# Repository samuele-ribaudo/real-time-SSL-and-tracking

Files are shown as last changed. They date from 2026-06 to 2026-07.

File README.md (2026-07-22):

# Real-Time Sound Source Localization and Tracking System

| Name | Matr. | Email |
|---|---|---|
| Samuele Ribaudo | 03821248 | samuele.ribaudo@tum.de |
| Hong Yan Jun  | 03813507 | go75kes@mytum.de |

> To see the engineering challenges we encountered and our solutions to overcome them, check out the [technical report ↗](documentation/technical_report.pdf)

## 1. Project structure

```text
.
├── code/                     # Project's firmware and STM32 build configuration
├── hardware/                 # Schematic files and custom structural designs
├── documentation/            # Academic documentation and project presentations
├── resources/                # External reference documentation
└── testing/                  # Standalone testing frameworks
```

> NOTE: every main directory in this repository contains a dedicated `README.md`. Please refer to those local files for thorough setup steps, configuration details, and specialized technical overviews relevant to each module.

---

## 2. Project overview

This project is a robotic "hearing" system that can detect where a sound is coming from and automatically turn to face it.

Using an STM32 microcontroller and two standard microphones, the system acts like a pair of human ears. When a person speaks, the system calculates the sound's origin and uses a servo motor to physically rotate the sensor array toward the speaker. It is designed to mimic a human neck's 180° range of motion. If a sound moves beyond what the system can physically reach, an onboard RGB LED signals a visual warning, acting as a modular trigger that would theoretically tell a larger humanoid robot to rotate its entire body.

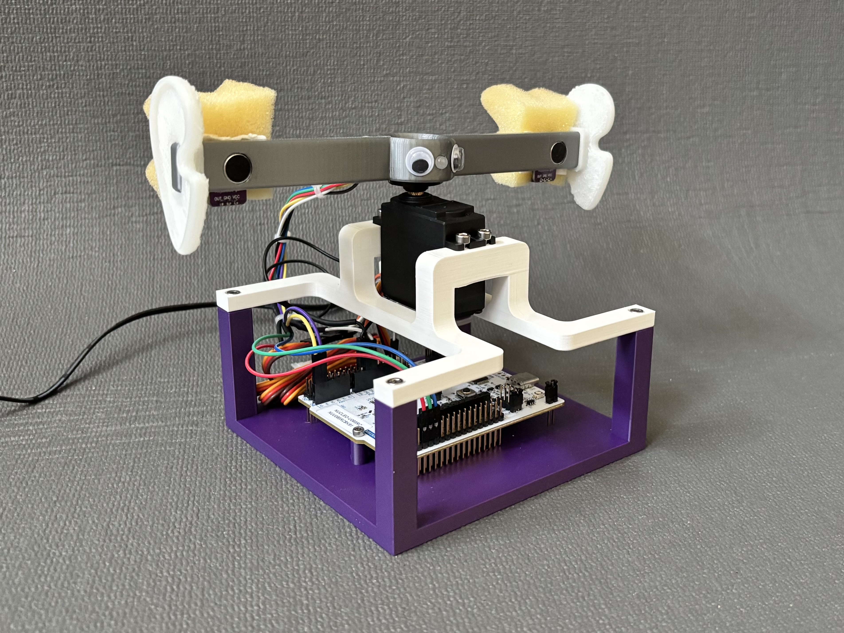
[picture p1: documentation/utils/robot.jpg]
acutal robot

> Figure: The final robotic project

---

## 3. Detailed system description

At a technical level, this project implements an embedded Sound Source Localization (SSL) and tracking system utilizing a NUCLEO-U083RC microcontroller developed within the STM32CubeIDE environment. The system continuously records environmental audio via two analog microphones spaced at a fixed distance. Using cross-correlation algorithms and digital filters, the system calculates the Time Delay of Arrival (TDOA) between the microphones to determine the precise azimuth angle of a human speaker.

To overcome the processing limitations of the micro controller and the physical realities of robotics, the system employs clever hardware-software design. It uses an acoustic foam baffle to eliminate the front-back "cone of confusion", calculates all math algorithms from scratch without relying on pre-built DSP libraries, and utilizes a strict "Listen-Compute-Move" state machine to prevent mechanical servo noise from corrupting the audio buffers. A 180° servo motor dynamically actuates the sensor array using a "relative-to-absolute" coordinate mapping to track the sound source.

---
## 4. Required materials & assembly

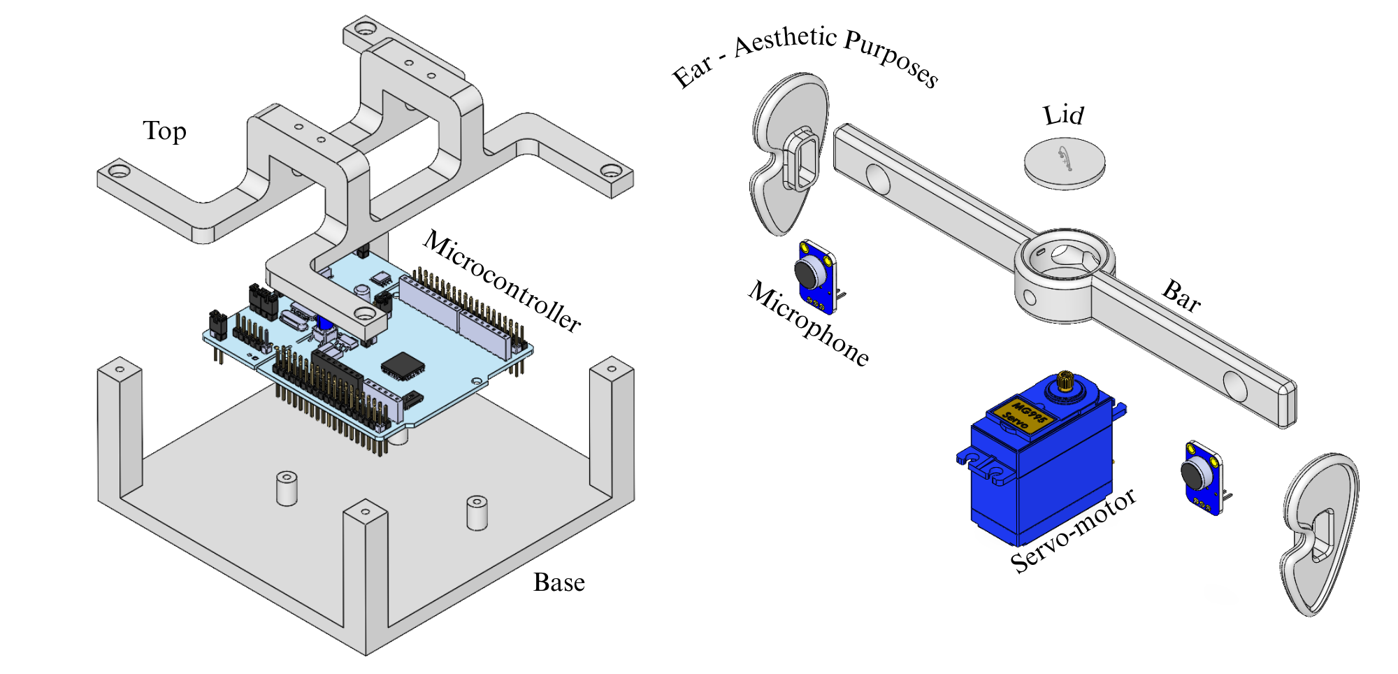
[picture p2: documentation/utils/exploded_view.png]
exploded view

> Figure: Exploded view of the system

| **Component** | **Qty** | **Description** |
| --- | --- | --- |
| NUCLEO-U083RC Development Board | 1 | The central processing unit of the system. It handles the high-speed ADC sampling via DMA, executes the mathematical cross-correlation algorithms, maintains the global coordinate tracking variables, and outputs the PWM control signals. | 
| MAX4466 analog microphones | 2 | Two independent analog microphones capture the environmental audio.|
| 180° servo motor | 1 | The mechanical actuator that rotates the sensor frame. |
| Acoustic foam block | 1 | High-density foam sponge to block rear audio signals. |
| RGB LED | 1 | A 4 pin RGB LED that provides real-time visual feedback of the state machine. It acts as a crucial flag for modular robotic design, flashing red when the target escapes the 180° physical field of hearing to trigger a "handoff" to a theoretical humanoid torso. |
| 330 Ohm resistor | 3 | Resistors placed in series with the RGB LED channels to prevent overcurrent damage. |
| PLA and TPU filament (3D Printing) | 1 | Material for printing the frame, board, servo mounts and ears (TPU). |
| Assorted wires | 1 | General circuit routing and power distribution. |

---
## 5. Physical connections & pin mapping

The system architecture utilizes dedicated hardware peripherals on the NUCLEO-U083RC board to handle high-speed data acquisition and actuation without blocking core application logic. The diagram below details the exact physical signal and power routing for each system component.

```text
                                ┌───────────────────────────────┐
                                │     STM32U083RC (Nucleo)      │                               5V power supply
                                │                               │                             ┌────────────────┐
                                │                          [GND]│─────────────────────────────│o  GND          │
                                │                          [VDD]│───┬─────────────────────────│o  5V           │
        Analog Left Mic         │                               │   │   180° Servo Morot      └────────────────┘
    ┌────────────────────┐      │                               │   │  ┌──────────────────┐
    │     OUT / Signal  o│─────>│[PC0]                          │   └──│o  VCC            │
    │              VCC  o│──────│[5V]                     [PA15]│─────>│o  PWM signal     │
    │              GND  o│──────│[GND]                     [GND]│──────│o  GND            │
    └────────────────────┘      │         ┌───────────┐         │      └──────────────────┘
                                │         │           │         │
        Analog Right Mic        │         │   STM32   │         │           RGB LED
    ┌────────────────────┐      │         │           │         │      ┌──────────────────┐
    │     OUT / Signal  o│─────>│[PC1]    └───────────┘   [PB13]│─────>│o  Red channel    │
    │              VCC  o│──────│[5V]                     [PB14]│─────>│o  Green channel  │
    │              GND  o│──────│[GND]                    [PB15]│─────>│o  Blue channel   │
    └────────────────────┘      │                          [GND]│──────│o  GND            │
                                │                               │      └──────────────────┘
                                └───────────────────────────────┘
```

To improve system readability and simplify debugging, we adopted a standardized, purpose-driven wire coloring scheme:

| Wire color | Purpose / Connection |
| --- | --- |
| White | Main 5V power supply line routed to the components. |
| Black | Common Ground (GND) connection to establish a shared reference plane. |
| Red | Digital control for the RGB LED Red channel. |
| Green | Digital control for the RGB LED Green channel. |
| Blue | Digital control for the RGB LED Blue channel. |
| Orange | Dedicated PWM signal line to control the 180° servo motor actuation. |
| Purple | Analog output signal transmission from the right microphone. |
| Yellow | Analog output signal transmission from the left microphone. |

---
## 6. MCU peripherals configuration

#### Timer 2 (PWM)

* **Clock Source**: Internal clock (16 MHz).
* **Channel 1**: PWM Generation CH1 (pin PA15).
* **Counter Settings**:
    * Prescaler (PSC): 15
    * Counter Mode: Up
    * Counter Period (ARR): 19999
    * Auto-reload preload: Enable

* **PWM Generation Channel 1**:
    * Mode: PWM mode 1
    * Pulse: 1500
    * CH Polarity: High

* **Configuration Logic**: Dividing the 16 MHz clock by 15 + 1 configures the timer to run at exactly 1 MHz, meaning 1 timer tick equals 1 microsecond. Counting to 19999 + 1 ticks creates a 20 ms period (50 Hz). Setting the initial Pulse to 1500 (1.5 ms) guarantees that the motor centers immediately upon power-up.

#### Timer 3 (ADC)

* **Clock Source**: Internal clock (16 MHz).
* **Counter Settings**:
    * Prescaler (PSC): 0
    * Counter Mode: Up
    * Counter Period (ARR): 319
    * Trigger Event Selection (TRGO): Update Event

#### ADC

* **Channels Enabled**: CH0 (PC0) and CH1 (PC1)
* **Resolution**: 12-bit resolution
* **External Trigger Conversion Source**: Timer 3 Trigger Out event (TRGO)
* **External Trigger Conversion Edge**: Rising Edge
* **Scan Conversion Mode**: Enabled
* **Number of Conversions**: 2

#### DMA

* **Direction**: Peripheral to memory
* **Mode**: Normal mode
* **Data Width**: 16-bit (half word)

#### GPIO LED

* **Pins**: PB13, PB14, and PB15 configured as GPIO Output.
* **Hardware Labels**: PB13 → LED_R, PB14 → LED_G, PB15 → LED_B.

---

## 7. The FSM & tracking logic breakdown

Because servo gears create acoustic noise, the system cannot listen and move at the same time. To address this limitation, the system relies on a strict, sequential FSM:

```mermaid
stateDiagram-v2
    direction TB
    
    [*] --> STATE_LISTEN
    
    %% Forward flow
    STATE_LISTEN --> STATE_COMPUTE : DMA buffer full
    STATE_COMPUTE --> STATE_ACTUATE : Sound detected OR<br>Inactivity timeout
    
    %% Branching out of ACTUATE
    STATE_ACTUATE --> STATE_OUT_OF_BOUNDS : Out-of-bounds<br>flag set
    STATE_ACTUATE --> STATE_SETTLE : Movement<br>within bounds
    
    %% Return paths (Grouped visually)
    STATE_COMPUTE --> STATE_LISTEN : No sound AND<br>Timeout pending
    STATE_SETTLE --> STATE_LISTEN : Mechanical delay<br>finished
    STATE_OUT_OF_BOUNDS --> STATE_LISTEN : Flashing finished
```
> Figure: State transition diagram for the acoustic localization and tracking pipeline.

* `STATE_LISTEN` (Blue): The servo is locked while the ADC+DMA pipeline records 1024 audio samples. Once the buffer is full, the DMA interrupt wakes the CPU and transitions the system to the compute phase.

* `STATE_COMPUTE` (Blue): Recording halts and the raw data is split and passed through the DSP pipeline.
    * If a sound is detected, the system calculates the angle offset, applies it to the current angle (flagging if it exceeds physical limits), and moves to `STATE_ACTUATE`.
    * If no sound is detected, the system checks an inactivity timeout. If the silence exceeds the maximum allowed time and the servo is not already centered, it targets the center position and moves to `STATE_ACTUATE`. Otherwise, it simply rolls back to `STATE_LISTEN`.

* `STATE_ACTUATE` (Green): The MCU updates the servo's position. If an out-of-bounds value was flagged during computation, the FSM transitions directly to `STATE_OUT_OF_BOUNDS`. If the movement is within normal limits, it proceeds to `STATE_SETTLE`.

* `STATE_SETTLE` (Green): A brief, blocking delay allows all mechanical servo vibrations to dissipate before the system safely loops back to `STATE_LISTEN`.

* `STATE_OUT_OF_BOUNDS` (Red Flash): The out-of-bounds flag is cleared, and the system flashes the red LED to provide a visual warning that the target exceeded the 180° physical limit. Once the flashing sequence finishes, it returns to `STATE_LISTEN`.

---

## 8. System validation and results

The digital signal processing (DSP) pipeline was fully validated on the NUCLEO-U083RC microcontroller, proving that the real-time cross-correlation and Time Delay of Arrival (TDOA) algorithms accurately track acoustic sources.

### 8.1 Signal filtering performance
To isolate human speech from environmental noise, the incoming audio passes through a custom 6th-order Butterworth bandpass filter (300 Hz to 3000 Hz). As shown below, the filter successfully suppresses low-frequency hums (100 Hz) and high-frequency noise (6 kHz), completely flattening the noise floor to provide clean signals for cross-correlation:

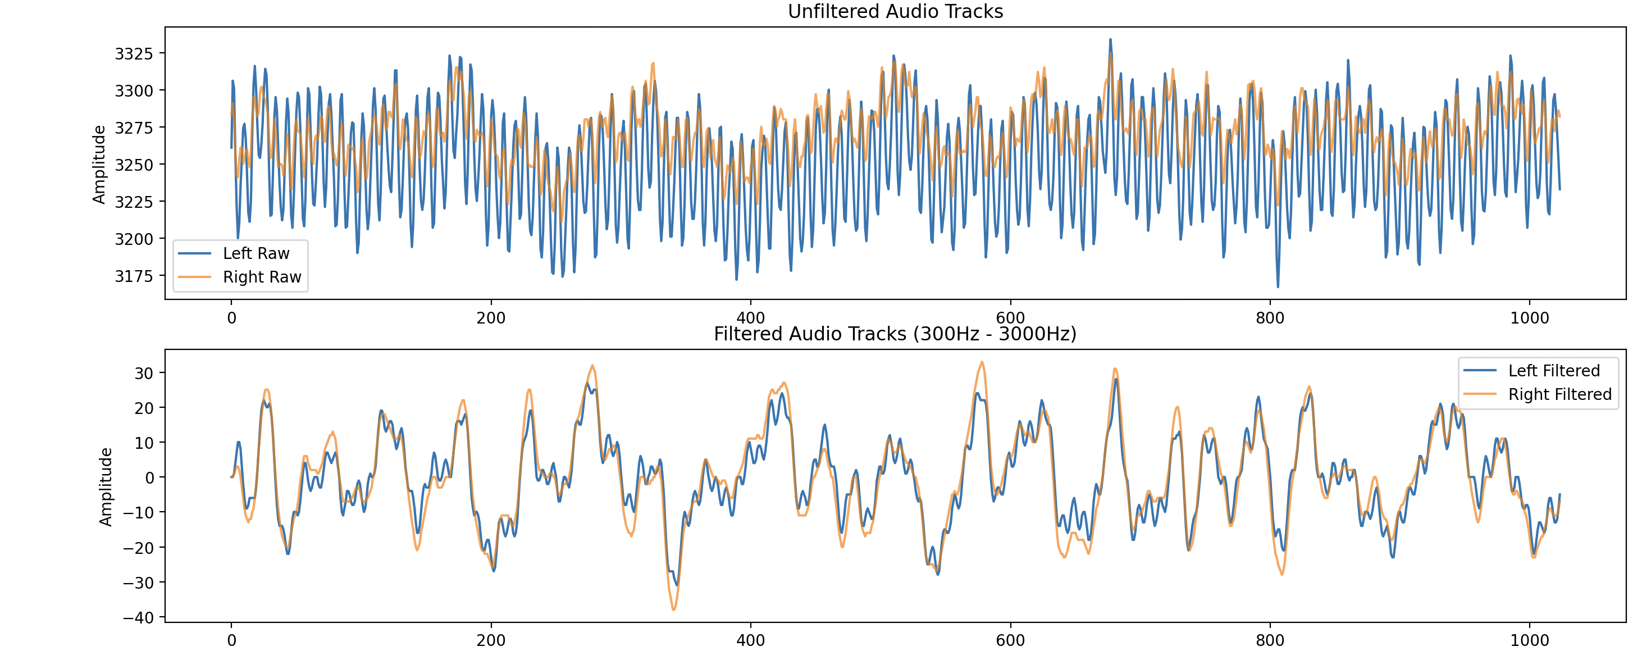
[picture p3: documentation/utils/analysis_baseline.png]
Signal Filtering Output

> Figure: Raw recording with environmental noise disturbances (top) and the resulting clean, flattened noise floor after 6th-order filtering (bottom).

### 8.2 Pipeline execution and sound tracking
When a sound is detected, the conditioned signals undergo a boundary-optimized cross-correlation to pinpoint the exact time delay. 

The system validation capture below highlights a successful test with a sound source on the right side. The pipeline filters out heavy background noise and produces a sharp, singular cross-correlation peak at a 22-sample lag. This precise shift allows the geometric logic to accurately calculate the angle and smoothly actuate the servo motor toward the target.

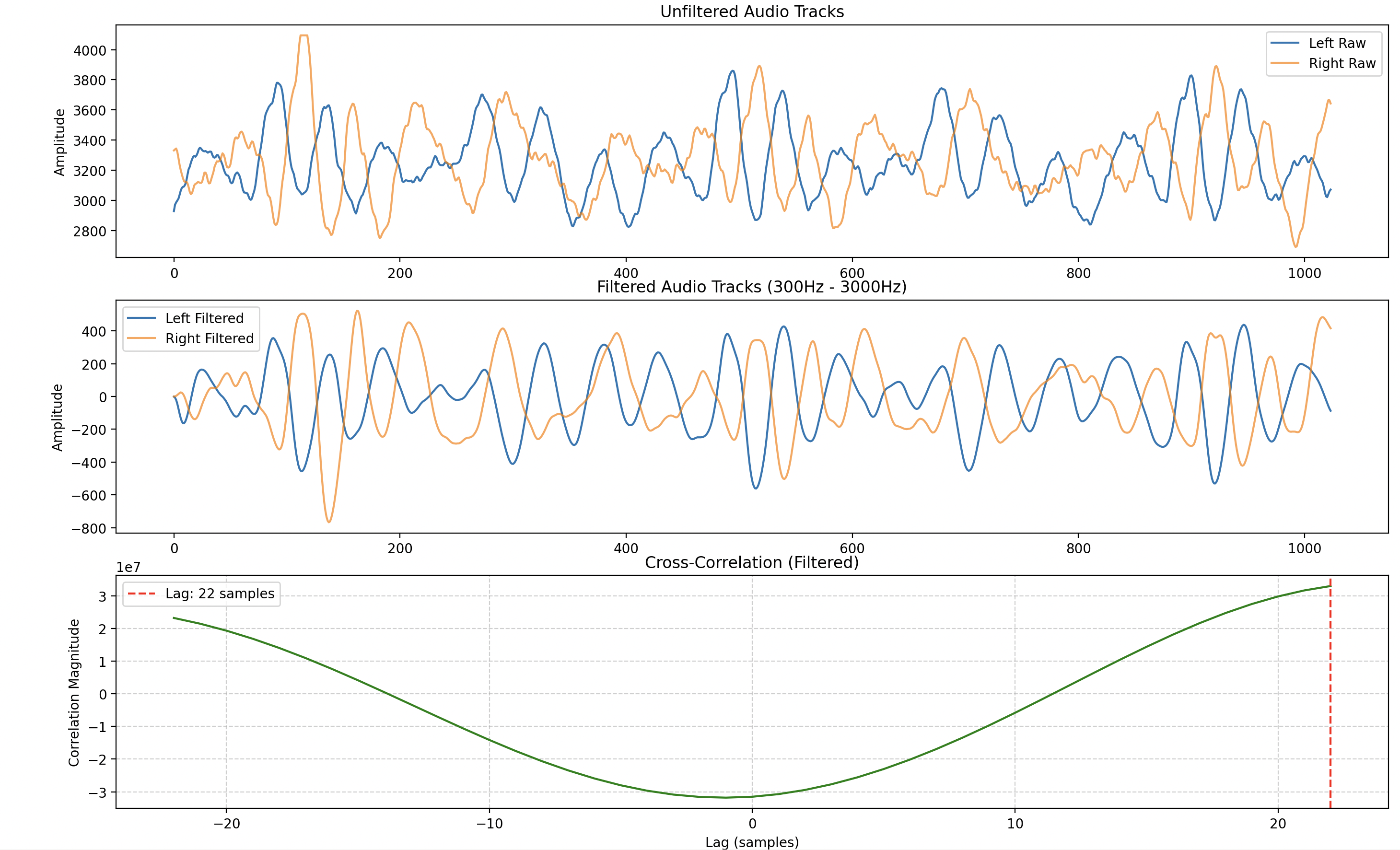
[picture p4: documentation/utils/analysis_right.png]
Pipeline and Cross-Correlation Validation

> Figure: Complete validation of a right-side tracking test showing raw signals (top), filtered speech waveforms (middle), and the distinct cross-correlation peak used for TDOA calculation (bottom).

---
## 9. Live system demonstration

To showcase the system's real-time capabilities in a practical environment, the following demonstration highlights it's core features:

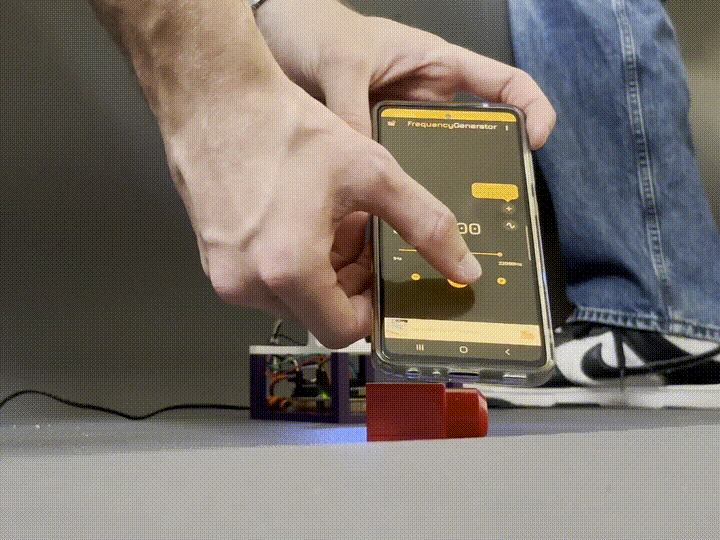
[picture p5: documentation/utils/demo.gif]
Live system demo

> Video: Real-time demonstration of the robotic hearing system reacting to finger snaps. ([Download MP4 version](documentation/demo.mp4))

This sequence validates three key system behaviors:
* **High-frequency noise rejection:** A smartphone plays a continuous 6000 Hz background noise. The system's digital filters effectively ignore this disturbance, allowing it to smoothly localize the sound of a human snapping their fingers.
* **Out-of-bounds warning:** When a finger snap occurs outside the physical 180° range of motion, the system correctly flags the out-of-bounds coordinate and flashes the onboard RGB LED red.
* **Inactivity reset:** After 5 seconds of complete silence, the inactivity timeout triggers, and the servo motor automatically resets to its default center position.

---

## 10. Conclusions

The development of the Real-Time Sound Source Localization and Tracking System yielded highly satisfactory results. The custom DSP pipeline executes entirely on the MCU and works exceptionally well to accurately calculate the Time Delay of Arrival (TDOA).

While 1D horizontal tracking is fully functional, the primary limitation of the current two-microphone array is the cone of confusion, which is the geometric ambiguity where sounds originating from the front and back (or at different elevations) produce identical time delays. 

To overcome this, future iterations of the project can explore two distinct paths for 3D localization:

* **Adding a third microphone**: Introducing a third microphone to form a planar triangular array. This extra spatial dimension would provide a secondary TDOA axis, completely resolving front/back ambiguity and enabling full 2D azimuth and elevation tracking.

* **Biomimetic spectral mapping**: Replicating the acoustic filtering of the human pinna (outer ear). By designing custom acoustic structures around the existing two microphones, incoming sound waves will bounce and attenuate differently depending on their angle of incidence. Because these unique spectral patterns modify the frequency response, a machine learning model or an AI-driven mapping pipeline could be trained to recognize these signatures, enabling true 3D localization using only two channels.

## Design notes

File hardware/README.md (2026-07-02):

# Structural CAD & 3D Printing Files

This directory contains the structural assembly models and 3D printable assets engineered for the microphone sensor array and servo motor tracking platform.

### 1. Repository layout

```text
hardware/
├── CAD/           # Native SolidWorks parametric design files
└── STL/           # Exported stereolithography files for manufacturing
```

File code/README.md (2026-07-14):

# Code - Real-Time Sound Source Localization

This directory contains the embedded C code for the STM32 NUCLEO-U083RC microcontroller. The software is responsible for sampling audio from two analog microphones via DMA, processing the signals using Digital Signal Processing (DSP) algorithms to find the Time Delay of Arrival (TDOA), and controlling a servo motor and RGB LED based on the localized sound source.

## Code Structure

The codebase is generated and structured using standard STM32Cube/CMake conventions. The following tree structure details the core components implemented for our project:

```text
code/
├── CMakeLists.txt                  # Build configuration file used by the VS Code STM32 extension
├── Core/
│   ├── Inc/
│   │   ├── config.h                 # Global system parameters, thresholds, and calibration constants
│   │   └── dsp_pipeline.h           # Header declaring custom DSP filtering and cross-correlation functions
│   └── Src/
│       ├── main.c                   # Main application loop, peripheral setup (ADC, DMA, TIM for PWM), and state machine
│       └── dsp_pipeline.c           # Custom DSP pipeline (discrete 300Hz - 3000Hz band-pass filter and cross-correlation)
...
```

> Note on generated files: all remaining files and directories (e.g., `stm32u0xx_it.c` in the `Core/` directory for Interrupt Service Routines; the `Drivers/` directory containing ST's official Hardware Abstraction Layer and ARM CMSIS/DSP libraries) are standard files automatically generated and managed by **STM32CubeMX** that we didn't modify.

## Setup, Build, and Flash Instructions

We use **Visual Studio Code** with the official **STM32 VS Code Extension** to build and flash this project.
These instructions have been tested on **Ubuntu 22.04**.

### Prerequisites & dependencies
#### 1. Build tools and ARM toolchain
Install build tools and the ARM toolchain by running the following commands in the terminal:
```bash
sudo apt update && sudo apt upgrade -y
sudo apt install git build-essential cmake ninja-build gcc-arm-none-eabi gdb-multiarch -y
```
#### 2. Flashing tools and USB drivers 
Install flashing tools and USB drivers by running the following command in the terminal:
```bash
sudo apt install openocd stlink-tools -y
sudo usermod -a -G plugdev,dialout $USER
```

> CRITICAL: After running these commands, log out and log back into the Ubuntu session (or restart your PC) for the group changes to take effect.

#### 3. Visual Studio Code & Extension packs
Download and install VS Code from [here](https://code.visualstudio.com/), or by running in the terminal:
```bash
sudo snap install code --classic
```

Open VS Code, go to Extensions tab (`Ctrl+Shift+X`), and search for both `C/C++ Extension Pack` by Microsoft and `STM32CubeIDE` by STMicroelectronic. Install them.

### Cloning the repository
1. Open your terminal.
2. Clone the repository.
```bash
git clone https://github.com/samuele-ribaudo/real-time-SSL-and-tracking.git
```
3. Navigate into the project folder.
```bash
cd real-time-SSL-and-tracking/code/
```
4. Open the project in VS Code.
```bash
code .
```
5. The STM32 Extension should detect the `CMakeLists.txt`. 

### Building
1. Click on the Build gear icon in the bottom left of the screen.
2. Select your build preset (usually `Debug`).
3. Look for a `Build finished with exit code 0` message in the terminal.

### Flashing
1. Connect your NUCLEO-U083RC board to your PC via the USB-C cable.
2. In the Run & Debug section (`Ctrl+Shift+D`), click `Run and Debug`. 
3. Select as debugger `STM32Cube: STM32 Launch STLink GDB Server`.
4. Once the debugger starts, click on the `Continue` arrow (`F5`) and flash the code onto the board.

### Standalone operation
Once the microcontroller has been successfully flashed, the system can operate independently of the PC debugger.
1. Disconnect the NUCLEO board from the PC (removing the USB-C debugging connection).
2. Provide external power to the system by plugging the dedicated wall adapter.
3. The system will initialize automatically. The servo will reset to its default center position, and the microphone array will immediately begin real-time environmental listening and localization.

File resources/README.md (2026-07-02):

# Resources Directory

This directory contains external documentation, reference manuals, and utility scripts used to support the design, hardware setup, and algorithmic implementation of the real-time sound source localization and tracking system.

---

### File registry

| File Name | Type | Description |
| --- | --- | --- |
| **`biquad_coefficients.m`** | MATLAB Script | Script used to design the 6th-order Butterworth bandpass filter (300 Hz - 3000 Hz) and generate the cascaded second-order sections (SOS) biquad coefficients formatted for direct C code integration.|
| **`UM3256_Nucleo64_User_Manual.pdf`** | Hardware Manual | Official STMicroelectronics user manual for the STM32 Nucleo-64 boards (specifically targeting the NUCLEO-U083RC layout), providing pin assignments, jumper configurations, and board schematics.|
| **`UM1940_HAL_LL_Drivers_Manual.pdf`** | Firmware Reference | Comprehensive description of the STM32 HAL and low-layer (LL) drivers, detailing driver files, peripheral handle data structures, and API processing workflows.|

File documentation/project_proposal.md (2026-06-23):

# Real-Time Sound Source Localization and Tracking System

| Name | Matr. | Email |
|---|---|---|
| Samuele Ribaudo | 03821248 | samuele.ribaudo@tum.de |
| Hong Yan Jun  | 03813507 | go75kes@mytum.de |

## 1. Project overview

This project is a robotic "hearing" system that can detect where a sound is coming from and automatically turn to face it.

Using an STM32 microcontroller and two standard microphones, the system acts like a pair of human ears. When a person speaks, the system calculates the sound's origin and uses a servo motor to physically rotate the sensor array toward the speaker. It is designed to mimic a human neck's 180° range of motion. If a sound moves beyond what the system can physically reach, an onboard RGB LED signals a visual warning, acting as a modular trigger that would theoretically tell a larger humanoid robot to rotate its entire body.

---

## 2. Detailed system description

At a technical level, this project implements an embedded Sound Source Localization (SSL) and tracking system utilizing a NUCLEO-U083RC microcontroller developed within the STM32CubeIDE environment. The system continuously records environmental audio via two analog microphones spaced at a fixed distance. Using cross-correlation algorithms and digital filters, the system calculates the Time Delay of Arrival (TDOA) between the microphones to determine the precise azimuth angle of a human speaker.

To overcome the processing limitations of the micro controller and the physical realities of robotics, the system employs clever hardware-software design. It uses an acoustic foam baffle to eliminate the front-back "cone of confusion", calculates all math algorithms from scratch without relying on pre-built DSP libraries, and utilizes a strict "Listen-Compute-Move" state machine to prevent mechanical servo noise from corrupting the audio buffers. A 180° servo motor dynamically actuates the sensor array using a "relative-to-absolute" coordinate mapping to track the sound source.

### Architectural execution modalities

To demonstrate architectural depth without relying on raw register-level manipulation, the project firmware leverages the STM32 Hardware Abstraction Layer (HAL) combined with advanced peripheral configurations:

* **Direct memory access (DMA):** Audio sampling bypasses the CPU entirely. Hardware Timers trigger the ADC to sample both microphones simultaneously directly into memory buffers, ensuring microsecond-level synchronization critical for acoustic math.
* **Manual algorithmic implementation:** All mathematical logic, including the band-pass filtering for human speech, the cross-correlation function for TDOA, and the local-to-global angular geometric conversions, are written completely from scratch in standard C.

---

## 3. Hardware architecture & signal routing

The system relies on fully isolated peripheral connections to the MCU to guarantee non-blocking operations and high-speed data acquisition.

```text
                            +---------------------------+
                            |    STM32U083RC (Nucleo)   |
                            |                           |
+--------------------+      |                           |      +--------------------+
| Analog Mic 1       |----->| [ADC Channel 1]           |      | 180° Servo Motor   |
| (Inside left ear)  |      |        |                  |----->| (Actuation)        |
+--------------------+      |     [DMA]                 | PWM  +--------------------+
             Analog Voltage |        |                  |
                            |        v                  |
+--------------------+      |   [SRAM Buffers]          |      +--------------------+
| Analog Mic 2       |----->|                           |      | RGB LED            |
| (Inside right ear) |      |                           |----->| (Status flag)      |
+--------------------+      | [Timer/PWM Generator]     | GPIO +--------------------+
                            | [GPIO Controller]         |
                            +---------------------------+

```

---

## 4. Components breakdown

**1. Nucleo-U083RC Microcontroller:**
The central processing unit of the system. It handles the high-speed ADC sampling via DMA, executes the mathematical cross-correlation algorithms, maintains the global coordinate tracking variables, and outputs the PWM control signals.

**2. Analog microphones (x2):**
Two independent analog microphones capture the environmental audio. They output a varying analog voltage proportional to the sound waves and are spaced at a known distance d inside the 3D-printed "ears" to allow for acoustic time delay calculations.

**3. Acoustic foam baffle:**
A physical block of sound-absorbing foam mounted directly behind the two microphones. This mechanical solution prevents mathematical front-back ambiguity by physically deafening the system to rear-originating sounds, perfectly matching the 180° physical range of the servo.

**4. 180° PWM servo motor:**
The mechanical actuator that rotates the sensor frame. Using a 180° servo instead of a continuous 360° motor protects the analog microphone wiring from snapping and provides absolute positional control via standard PWM duty cycles.

**5. RGB LED:**
A 4 pin RGB LED that provides real-time visual feedback of the state machine. It acts as a crucial flag for modular robotic design, flashing red when the target escapes the 180° physical field of hearing to trigger a "handoff" to a theoretical humanoid torso.

**6. 3D Printed frame elements:**
Custom PLA components including the structural mounts for the microphones, the acoustic foam, and the servo motor, stylized with two outer "ears".

---

## 5. The FSM & tracking logic breakdown

Because servo gears create immense acoustic noise, the system cannot listen and move at the same time. The finite state machine (FSM) runs sequentially:

**`STATE_LISTEN` (Blue LED):** The servo is locked in place. The ADC+DMA pipeline is activated to record 1024 samples.

**`STATE_COMPUTE`(Blue LED):** Audio recording stops. The MCU applies a band-pass filter to check for human speech frequencies. If the audio passes the threshold, cross-correlation is performed to calculate the relative angle.

**`STATE_ACTUATE` (Green LED):** The MCU maps the relative angle to the global coordinate frame and updates the Timer PWM duty cycle.

**`STATE_SETTLE`(Green LED):** A non-blocking delay allows the mechanical vibrations of the servo to dissipate before returning to `STATE_LISTEN`.

**`STATE_OUT_OF_BOUNDS` (Red LED flashing):** Triggered when the calculated angle exceeds physical limits. The system flashes the red LED for 1.5 seconds before automatically transitioning back to `STATE_LISTEN`.

**Crucial variables for relative tracking and limits:**

* `current_servo_angle`: Stores the absolute position (0° to 180°) of the platform relative to the room.
* `relative_angle`: The calculated offset from the microphones (-90° to +90°).
* **Limit logic & timeout reset:** The software calculates `new_angle = current_servo_angle + relative_angle`. If `new_angle` exceeds 180° or drops below 0°, the FSM transitions to `STATE_OUT_OF_BOUNDS` to flash the red LED for 1.5 seconds. If no sound is detected within the tracking cone for 5 seconds, the system automatically resets `current_servo_angle = 90` and returns to a center resting position.

---

## 6. Workload distribution & task definition

#### **[Samuele]: Setup, FSM & application logic**
 * **STM32CubeMX peripheral configuration:** Configure the core hardware initialization, including dual ADC channels, normal mode DMA streams, Hardware Timers (e.g. for PWM generation), and GPIOs for the RGB LED. Generate the baseline project skeleton.

 * **State machine implementation:** Program the core main.c architecture, managing the sequential transitions between STATE_LISTEN, STATE_COMPUTE, STATE_ACTUATE, STATE_SETTLE, and STATE_OUT_OF_BOUNDS. Handle the DMA interrupt callbacks to orchestrate data handoffs safely.

 * **Geometric angle calculation:** Take the raw sample offset provided by Ryan's algorithm and calculate the relative azimuth angle $\theta$ using the geometric formula: 
 $$\theta = \arcsin\left(\frac{\Delta t \cdot v}{d}\right)$$
   
 * **Actuation, safety controls & limits:** Map the calculated absolute angle to the corresponding Timer PWM duty cycle for the servo. Implement the 0° to 180° software clamping limits, the 1.5-second `STATE_OUT_OF_BOUNDS` non-blocking recovery timer, the 5-second inactivity timeout reset, and the specific RGB color triggers for each state.

#### **[Ryan]: Hardware, fabrication & DSP algorithms**

 * **CAD design & fabrication:** Design the 3D-printable structural mounts for the servo motor, the acoustic foam baffle, and the external "ears."

 * **Physical assembly & circuit wiring:** Build the physical prototype. Wire the two analog microphones, the RGB LED, and the servo motor to the Nucleo board, ensuring solid power delivery and shared grounds.

 * **Manual filtering algorithms:** Write a custom C implementation of a discrete band-pass filter (approx. 300 Hz - 3000 Hz) to isolate human speech frequencies from background noise. Include an amplitude threshold function to keep the pipeline idle when the room is quiet.

 * **Cross-correlation & TDOA:** Implement the time-domain cross-correlation algorithm from scratch. This function will ingest the raw audio buffers provided by Samuele's DMA pipeline, compare them, and output the exact sample offset.

---

## 7. Required materials & sourcing

| **Material component Description** | **Qty** | **Target application / Notes** | **Sourcing / Cost** |
| --- | --- | --- | --- |
| NUCLEO-U083RC Development Board | 1 | Main STM32 microcontroller unit | Lab inventory |
| MAX4466 analog microphones | 2 | Analog microphones for capturing audio | Lab inventory) |
| SG90 180° servo motor | 1 | Positional actuator for rotating the sensor platform | Lab inventory |
| Acoustic foam block | 1 | High-density foam sponge to block rear audio signals | Probably in the trash |
| RGB LED | 1 | 4 pin LED for FSM state and limit reached indication | Lab inventory |
| PLA filament (3D Printing) | 1 | Material for printing the frame, ears, and servo mounts | Lab inventory |
| Assorted wires & breadboard | 1 | General circuit routing and power distribution | Lab inventory |

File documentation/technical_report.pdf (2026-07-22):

Chair for Cognitive Systems
Department of Electrical and Computer Engineering Technical University of Munich

## Real-Time Sound Source Localizer and Tracking System

Technical report of the final project for Humanoid Sensors and Actuators

Samuele Ribaudo B and Hong Yan Jun B

M.Sc. Mechatronics, Robotics and Biomechanical Engineering, Technical University of Munich B samuele.ribaudo@tum.de
B go75kes@mytum.de

July 22, 2026

Abstract — This document serves as technical report for the Real-Time Sound Source Localization and Tracking System, detailing the engineering challenges we encountered and how we overcome them.

## Contents

1 Introduction | 2
2 MCU Configuration (Samuele) | 2
3 Application logic (Samuele) | 3
4 CAD design (Ryan) | 4
5 Hardware fabrication (Ryan) | 5
6 Signal filtering & testing framework (Samuele) | 6
7 DSP pipeline (Ryan) | 7
8 Conclusions | 8

## 1 Introduction

This project is a robotic "hearing" system that can detect where a sound is coming from and automatically turn to face it. Using an STM32 microcontroller and two standard microphones, the system acts like a pair of human ears. When a person speaks, the system calculates the sound’s origin and uses a servo motor to physically rotate the sensor array toward the speaker. It is designed to mimic a human neck’s 180◦ range of motion. If a sound moves beyond what the system can physically reach, an onboard RGB LED signals a visual warning, acting as a modular trigger that would theoretically tell a larger humanoid robot to rotate its entire body.


Figure 1 The final robotic project.

## 2 MCU Configuration (Samuele)

The Nucleo board was configured via the STM32CubeMX visual configurator to generate the base C project. Complete peripheral settings are detailed in section 6 of the repository’s README. (https://github.com/samuele-ribaudo/real-time-SSL-and-tracking/blob/main/README.md)

### 2.1 Sampling frequency and ADC triggering (Timer 3)

One of the first challenges was determining the optimal microphone sampling frequency, balancing spatial resolution with physical memory constraints.

Given a microphones distance of d = 0.15 m, and a speed of sound v = 343 m/s, the maximum time delay between channels is ∆tmax = d/v ≈ 437 µs. A standard 16 kHz audio sampling rate (ts = 62.5 µs) yields a maximum offset of 437/62.5 ≈ 7 samples on each side, for a total range of 14 samples, limiting our servo angular resolution to a coarse 13◦

(180◦/14). To achieve finer angular control, a higher sampling frequency was required.

However, our memory limits us to 1024-sample buffers. Extremely high sampling rates (e.g., 1 MHz) would fill the buffer in approximately 1 ms. This short recording window causes two major issues: the lower frequencies of human speech cannot be properly captured for the DSP pipeline (e.g., a 300 Hz wave requires ≈ 3.3 ms for a full period), and there is a high risk of only capturing the silences between spoken letters.

To find the sweet spot between accurate fine-grained servo positioning and sufficient audio recording length, we settled on a sampling frequency of 50 kHz. This yields an audio track of approximately 20 ms, which is long enough to capture about six full wave periods of human voice at 300 Hz, while drastically improving the angular resolution to approximately 4

◦
. Based on these considerations, Timer 3 was configured to trigger the ADC conversions at a 50 kHz frequency.

### 2.2 Analog-to-Digital Converter (ADC) & DMA

To guarantee high-speed, non-blocking data acquisition, the 12-bit ADC operates in scan mode, capturing both microphone channels simultaneously on the Timer 3 trigger. Crucially, data is routed directly to memory via Direct Memory Access (DMA). This completely offloads the CPU during the listening phase, ensuring microsecond-level synchronization without computational bottlenecks.

### 2.3 Servo motor actuation (Timer 2)

Timer 2 is configured to generate the 50 Hz PWM signal required for the 180◦
servo motor. By prescaling the internal 16 MHz clock, we achieve a 1 µs timer resolution. We configured an initial 1.5 ms PWM pulse to guarantee that the servo safely snaps to the exact 90◦
center position immediately upon power-up, preventing erratic startup movements.

### 2.4 Status indication (GPIO)

Three standard GPIO output pins are mapped to the onboard RGB LED. This provides a simple, interruptfree method for real-time visual feedback of the system’s finite state machine transitions.

## 3 Application logic (Samuele)

### 3.1 Codebase organization

To organize the auto-generated STM32CubeMX code, we moved all hardware initialization into a single stm32cubeMX_setup(void) wrapper function and we removed all the unnecessary comments, keeping main.c clean. Additionally, we created a config.h file to store all tunable parameters and physical constants in one place, making it easy to adjust system settings at compile time.

To maintain a clean and readable main loop, we abstracted key operations into dedicated helper functions for LED control, audio data splitting, angle computation, and servo actuation.

### 3.2 Finite State Machine (FSM)

Because servo gears create acoustic noise, the system cannot listen and move at the same time. To address this limitation, the system relies on a strict, sequential FSM:

- STATE_LISTEN (Blue): The servo is locked while the ADC+DMA pipeline records 1024 audio samples. Once the buffer is full, the DMA interrupt wakes the CPU and transitions the system to the compute phase.
- STATE_COMPUTE (Blue): Recording halts and the raw data is split and passed through the DSP pipeline.

– If a sound is detected, the system calculates the angle offset, applies it to the current angle (flagging if it exceeds physical limits), and moves to STATE_ACTUATE .

– If no sound is detected, the system checks an inactivity timeout. If the silence exceeds the maximum allowed time and the servo is not already centered, it targets the center position and moves to STATE_ACTUATE . Otherwise, it simply rolls back to STATE_LISTEN .

- STATE_ACTUATE (Green): The MCU updates the servo’s position. If an out-of-bounds value was flagged during computation, the FSM transitions directly to STATE_OUT_OF_BOUNDS . If the movement is within normal limits, it proceeds to STATE_SETTLE .
- STATE_SETTLE (Green): A brief, blocking delay allows all mechanical servo vibrations to dissipate before the system safely loops back to STATE_LISTEN .
- STATE_OUT_OF_BOUNDS (Red Flash): The out-of-bounds flag is cleared, and the system flashes the red LED to provide a visual warning that the target exceeded the 180◦ physical limit. Once the flashing sequence finishes, it returns to STATE_LISTEN .

## 4 CAD design (Ryan)


Figure 2 Exploded view of the system.

For the CAD design, we started with a first sketch and then bring it into 3-dimensional space with Solidworks. The first design was a proof of concept so that we could be sure that the system could actually be implemented physically and all the components could be connected functionally with each other. We started designing the system with a rough estimate of the measurements because we did not have the components yet. After receiving the components, we had to implement the correct measurements in our design, such that once the first design has been materialized and our first prototype was fully functional, we switch our focus on the aesthetic aspect of the design to make look cooler instead of just square edges everywhere. In the first design, the cables connection were quite messy, so we decided to hide them away in the bar as this will give the system a much cleaner look.

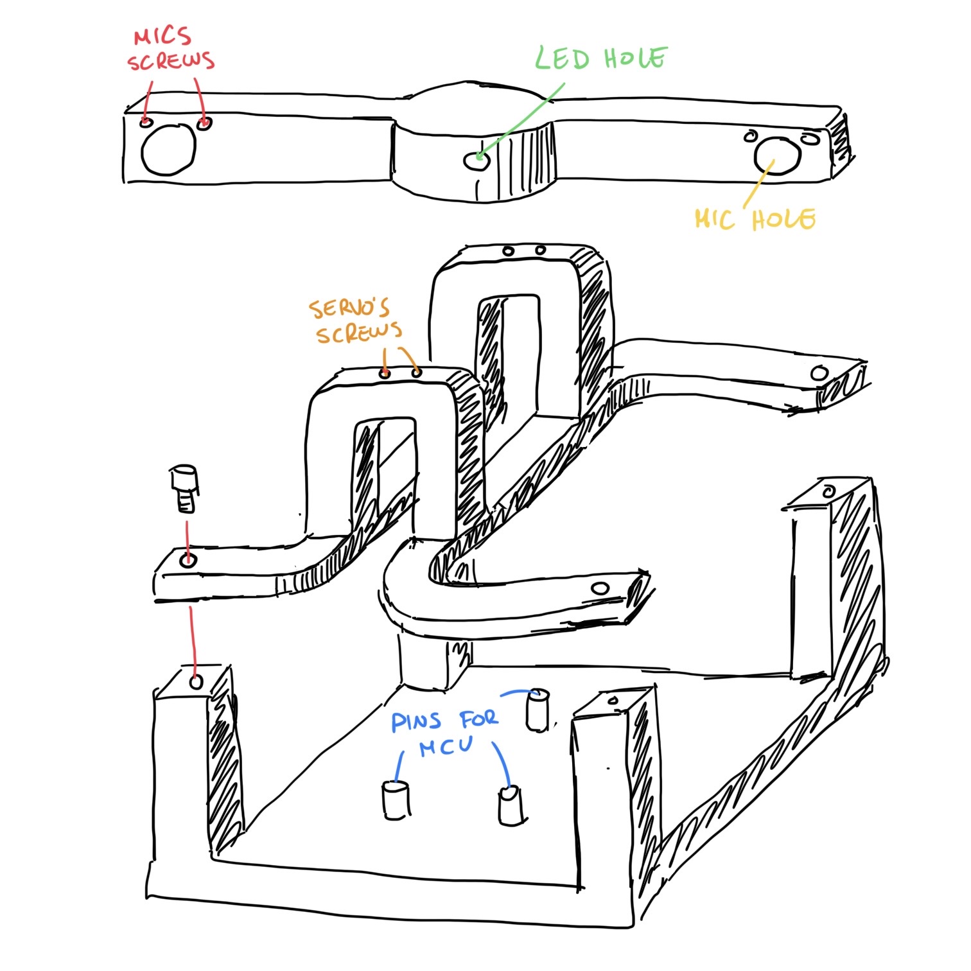
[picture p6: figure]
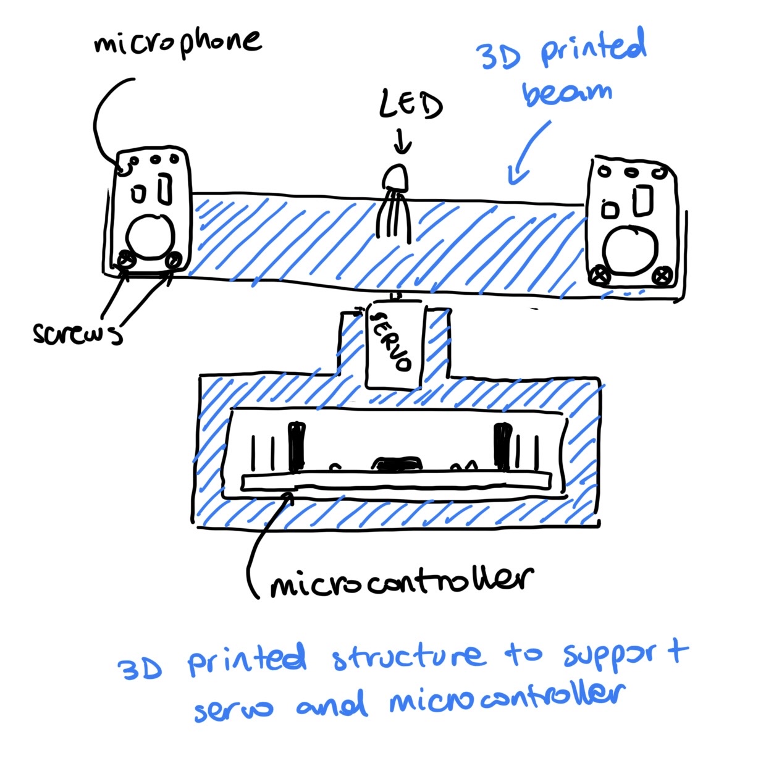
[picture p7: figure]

(a) Concept sketch 1. | (b) Concept sketch 2.

Figure 3 Initial sketches and brainstorming.

## 5 Hardware fabrication (Ryan)

### 5.1 Signal routing and physical connections

The diagram below details the exact physical signal and power routing for each system component.

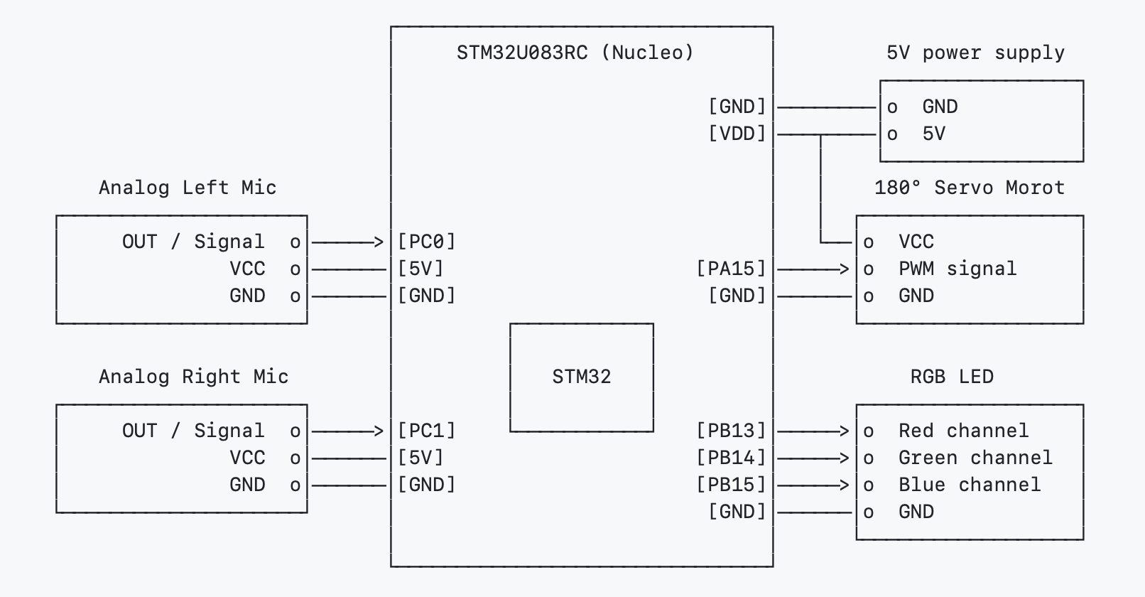
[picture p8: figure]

Figure 4 Physical signal and power routing diagram.

### 5.2 Connections

In the initial prototyping phase, the components were connected using traditional jumper cables and a breadboard.

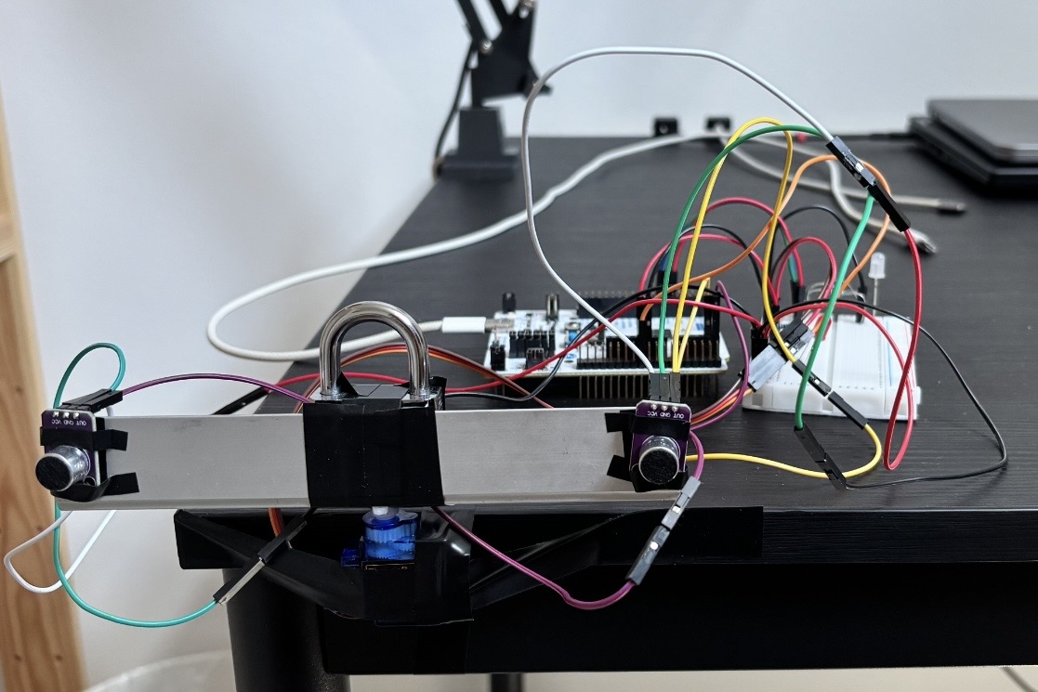
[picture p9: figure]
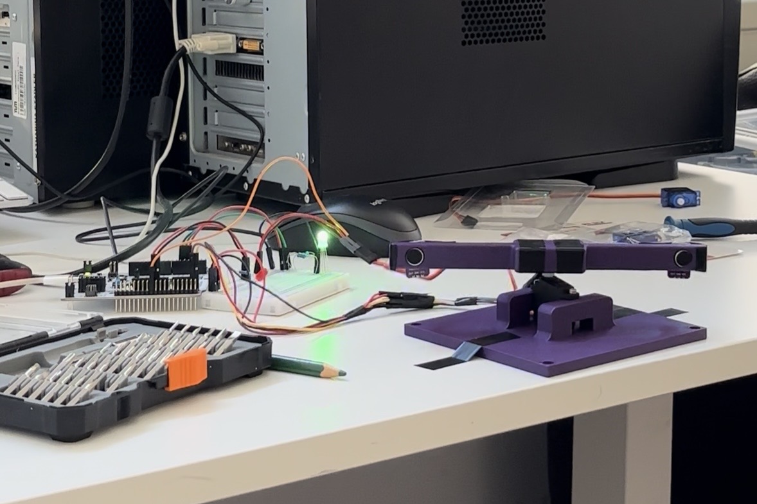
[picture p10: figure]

(a) Initial breadboard verification. | (b) Integrated 3D printed prototype.

Figure 5 Initial breadboard verification showing raw jumper routing (Left). Second prototype iteration showing a cleaner structural design with integrated 3D-printed mounts (Right).

To reduce the system’s footprint and eliminate the need for a bulky external breadboard, we soldered the common grounds and VCC connections directly into unified lines. Additionally, 330 Ω current-limiting resistors were embedded directly inside the wires leading to the RGB LED channels to protect the hardware from overcurrent damage.

To improve system readability and simplify debugging, we adopted a standardized, purpose-driven wire coloring scheme:

Table 1 Standardized Wire Color Scheme

Wire Color | Purpose / Connection
White | Main 5V power supply line routed to the components.
Black | Common Ground (GND) to establish a shared reference plane.
Red | Digital control for the RGB LED Red channel.
Green | Digital control for the RGB LED Green channel.
Blue | Digital control for the RGB LED Blue channel.
Orange | PWM signal line to control the 180◦ servo motor actuation.
Purple | Analog output signal transmission from the right microphone.
Yellow | Analog output signal transmission from the left microphone.

### 5.3 The servo challenge

Another hardware challenge involved the original servo motor, which suffered from aggressive perturbations at the 90◦
center position due to insufficient holding torque. To address this, we upgraded to a larger, higher-torque actuator. However, this new motor required a higher operating current than the Nucleo board could safely supply.

To resolve this without destabilizing the system, we engineered an external power distribution architecture by repurposing a standard 5V wall adapter. We modified the cable termination to solder a shared ground line that is plugged directly to the board’s GND pin, establishing a common reference plane, while splitting the positive power rail into two dedicated connections. The first positive line routes directly to the servo’s VCC input to isolate its heavy electrical load from the microcontroller, while the second connects directly to the board’s power pin (VDD). This custom wiring harness successfully decoupled the actuator’s power draw, eliminated the voltage-induced perturbations, and allowed the system to operate autonomously without relying on a PC USB connection.

## 6 Signal filtering & testing framework (Samuele)

### 6.1 Microphone validation & data collection

To validate our Sound Source Localization (SSL) algorithms, we developed a data collection framework ( testing/microphone_data_collector ). We recorded baseline audio tracks from the analog microphones in a quiet room, and with a human voice originating from the left, center, and right. These recordings allowed us to verify synchronous audio capture, physically adjust the MAX4466 hardware gain, and establish a reliable "quiet room" amplitude threshold to keep the finite state machine idle during silence.

### 6.2 Python ground truth & C/C++ DSP verification

Once the baseline was established, we introduced complex environmental disturbances into our recordings. We captured new voice samples from various angles while simultaneously playing a 100 Hz lowfrequency hum and a 6 kHz high-frequency noise. These noisy samples were first processed using Python DSP libraries to establish a mathematical ground truth.

Then we built a standalone C-based DSP testing framework ( testing/dsp_pipeline_test ). It ingests the raw CSV data, processes it through our custom C/C++ pipeline, and exports the results. A Python script ( plot_audio.py ) visualized these outputs, allowing us to benchmark our embedded C algorithms against the Python ground truth before flashing the code to the STM32.

### 6.3 Filter design and iterations

The pipeline relies on a bandpass filter to isolate human speech (approximately 300 Hz to 3000 Hz). We initially implemented a 2nd-order biquad filter, using MATLAB’s butter function to generate the coefficients. However, testing revealed this lacked the steep roll-off required. The 6 kHz high-frequency disturbance was not attenuated enough, passing through the filter and severely corrupting the cross-correlation stage.

This produced a sparse, noisy array with ambiguous peaks, causing the system to calculate incorrect time delays.

To resolve this, we upgraded the architecture to a 6th-order Butterworth filter, again utilizing MATLAB to compute the cascaded coefficients. This filter yielded highly satisfactory results, successfully suppressing both the 100 Hz and 6 kHz disturbances. As shown below, the filter effectively flattens the noise floor in a quiet room:


Figure 6 Unfiltered quiet room recording with 100 Hz and 6 kHz disturbances (top) and the resulting flattened noise floor after 6th-order bandpass filtering (bottom).

## 7 DSP pipeline (Ryan)

The DSP architecture executes entirely on the STM32 during the STATE_COMPUTE window, processing two 1024-sample raw ADC buffers to calculate the Time Delay of Arrival (TDOA) without relying on external libraries. To meet strict real-time MCU constraints, the pipeline is divided into three optimized stages:

### 7.1 Event Detection (Amplitude Thresholding)

To prevent the MCU from continuously running heavy arithmetic on background noise, the pipeline acts as a gatekeeper. It calculates the peak-to-peak amplitude (max − min) of the incoming buffers. If the spread falls below the established ambient noise floor, the pipeline aborts to save power and processing time.

### 7.2 Zero-Phase Signal Conditioning

Because raw microphone data contains a positive DC voltage offset, the signal must be conditioned. Initial implementations using an IIR Biquad Band-Pass filter (300 Hz − 3000 Hz) caused frequency-dependent phase distortion ("ringing"), which temporally misaligned the acoustic waves and corrupted the cross-correlation output. To solve this, we implemented a zero-phase Mean-Centering approach: the MCU calculates the discrete baseline average of the 1024 samples and subtracts it, perfectly centering the wave at zero using safe integer arithmetic.

### 7.3 Boundary-Optimized Cross-Correlation

Standard cross-correlation of two 1024-sample arrays requires over 1,000,000 operations, exceeding real-time limits. However, given the physical microphone spacing (d = 0.15 m) and the speed of sound, the absolute maximum theoretical time delay between the two ears is just ±22 samples. By strictly bounding the search loop to this physical constraint, the algorithm’s workload is reduced to just ∼ 45 iterations. The discrete lag index that produces the highest correlation score is then returned to the geometric control logic.

### 7.4 Pipeline validation

The DSP pipeline is fully functional. With the environmental noise successfully attenuated, the cross-correlation of the filtered signals produces a singular, well-defined peak, allowing the system to accurately actuate the servo motor.


Figure 7 Validation of the working pipeline during a right-side sound test. It displays the unfiltered raw audio tracks with disturbances (top), the cleanly filtered signals between 300 Hz and 3000 Hz (middle), and the resulting cross-correlation (bottom) demonstrating a well-defined peak at a 22-sample lag for precise TDOA calculation.

### 7.5 TDOA and angle calculation

The calculation of the sound source’s angle is handled by the compute_angle_offset() function defined inside code/Core/Src/main.c . Once the time delay ∆t is derived from the sample offset, calculating the relative azimuth angle θ is a straightforward application of the following geometric formula:

θ = arcsin

∆t · v
d

Even though harder to read, we deliberately chose to perform and maintain all angular calculations in radians. Because the standard C math library’s asinf() function inherently returns a value in radians, using radians as our system’s base unit of measure (e.g., defining the SERVO_MAX_ANGLE directly as π) allows us to avoid the unnecessary computational overhead that would be required to convert the values into degrees.

## 8 Conclusions

### 8.1 Live demo

The development of the Real-Time Sound Source Localization and Tracking System yielded highly satisfactory results. The custom DSP pipeline executes entirely on the MCU and works exceptionally well to accurately calculate the Time Delay of Arrival (TDOA).

To showcase the system’s real-time capabilities in a practical environment, the video demonstration highlights its core features. This sequence validates three key system behaviors:

- High-frequency noise rejection: A smartphone plays a continuous 6000 Hz background noise. The system’s digital filters effectively ignore this disturbance, allowing it to smoothly localize the sound of a human snapping their fingers.
- Out-of-bounds warning: When a finger snap occurs outside the physical 180◦
range of motion, the
system correctly flags the out-of-bounds coordinate and flashes the onboard RGB LED red.
- Inactivity reset: After 5 seconds of complete silence, the inactivity timeout triggers, and the servo motor automatically resets to its default center position.

### 8.2 Future improvements

While 1D horizontal tracking is fully functional, the primary limitation of the current two-microphone array is the cone of confusion, which is the geometric ambiguity where sounds originating from the front and back (or at different elevations) produce identical time delays.

To overcome this, future iterations of the project can explore two distinct paths for 3D localization:

- Adding a third microphone: Introducing a third microphone to form a planar triangular array. This extra spatial dimension would provide a secondary TDOA axis, completely resolving front/back ambiguity and enabling full 2D azimuth and elevation tracking.
- Biomimetic spectral mapping: Replicating the acoustic filtering of the human pinna (outer ear). By designing custom acoustic structures around the existing two microphones, incoming sound waves will bounce and attenuate differently depending on their angle of incidence. Because these unique spectral patterns modify the frequency response, a machine learning model or an AI-driven mapping pipeline could be trained to recognize these signatures, enabling true 3D localization using only two channels.

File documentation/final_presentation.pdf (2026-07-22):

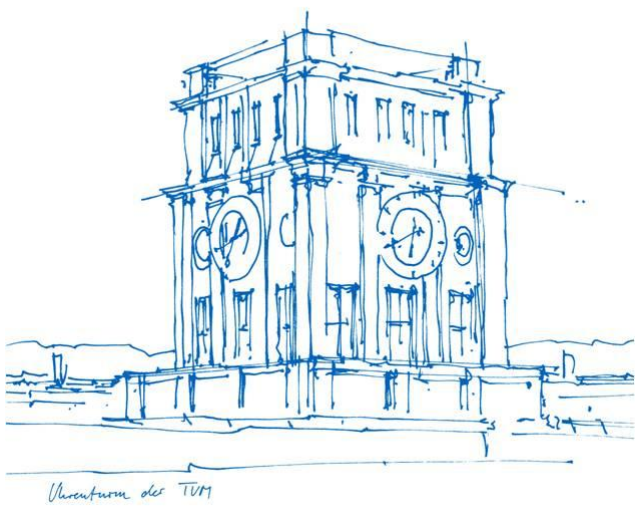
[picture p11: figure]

Humanoid Sensors and Actuators - Final Project | Samuele Ribaudo & Hong Yan Jun

# Real Time SSL and Tracking System

## Presented by Samuele Ribaudo and Hong Yan Jun

# Introduction

## Robotic “hearing system”

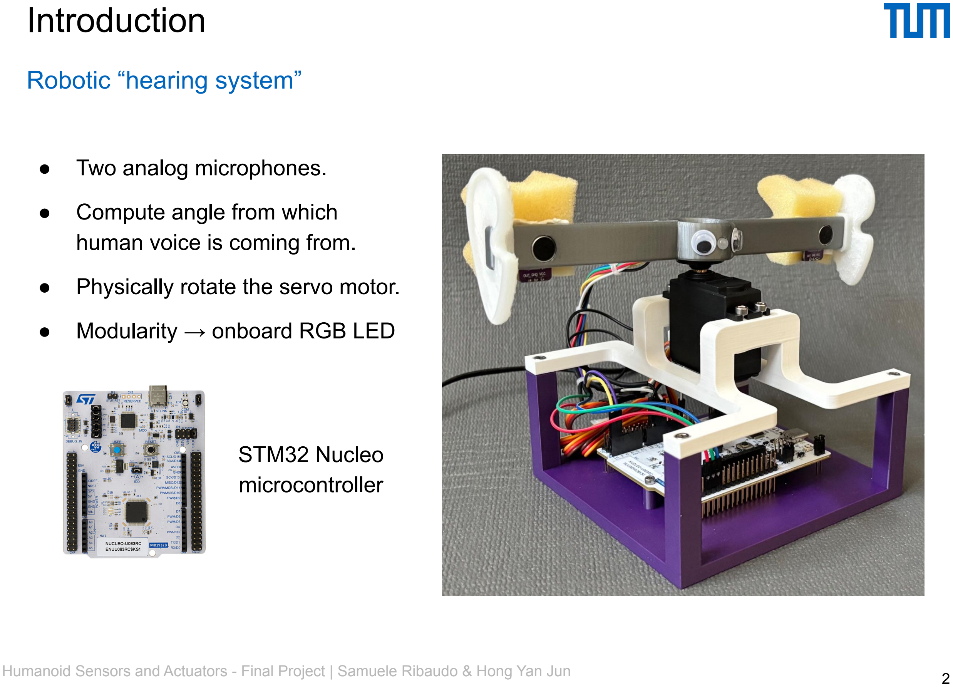
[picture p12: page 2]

- Two analog microphones.

## - Compute angle from which

human voice is coming from.

- Physically rotate the servo motor.

## - Modularity → onboard RGB LED

## STM32 Nucleo microcontroller

# MCU configuration & application logic

## First challenge

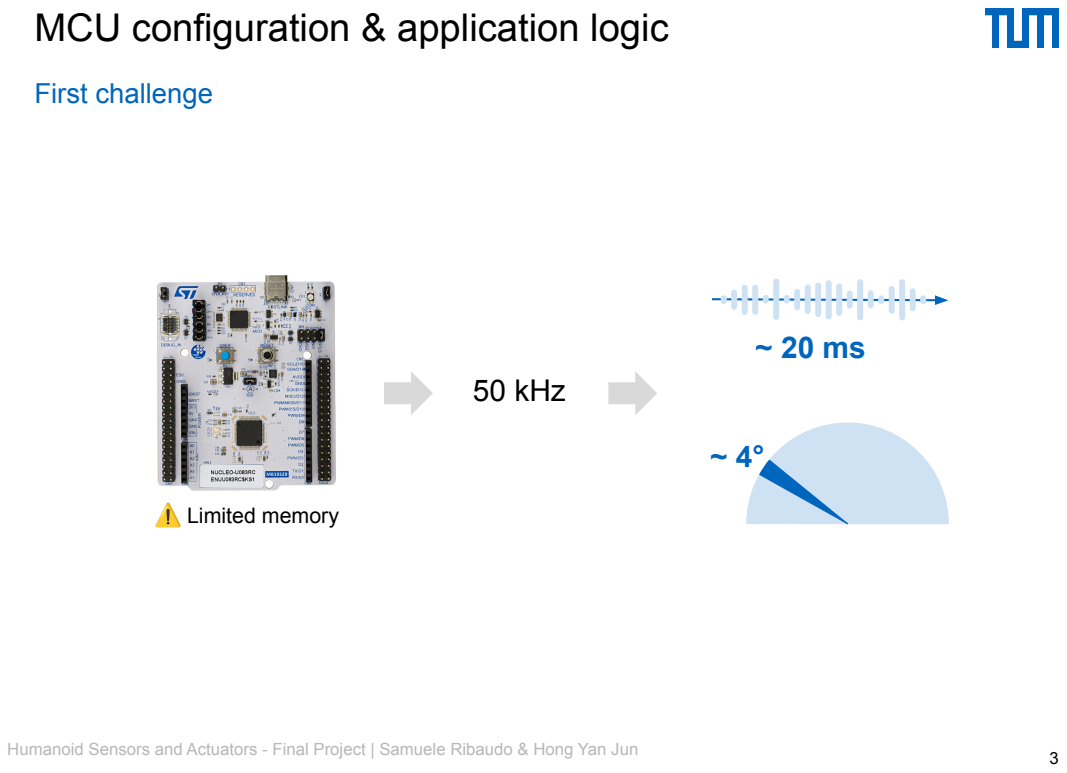
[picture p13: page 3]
Humanoid Sensors and Actuators - Final Project | Samuele Ribaudo & Hong Yan Jun; 50 kHz; Limited memory

# MCU configuration & application logic

## Need for a FSM

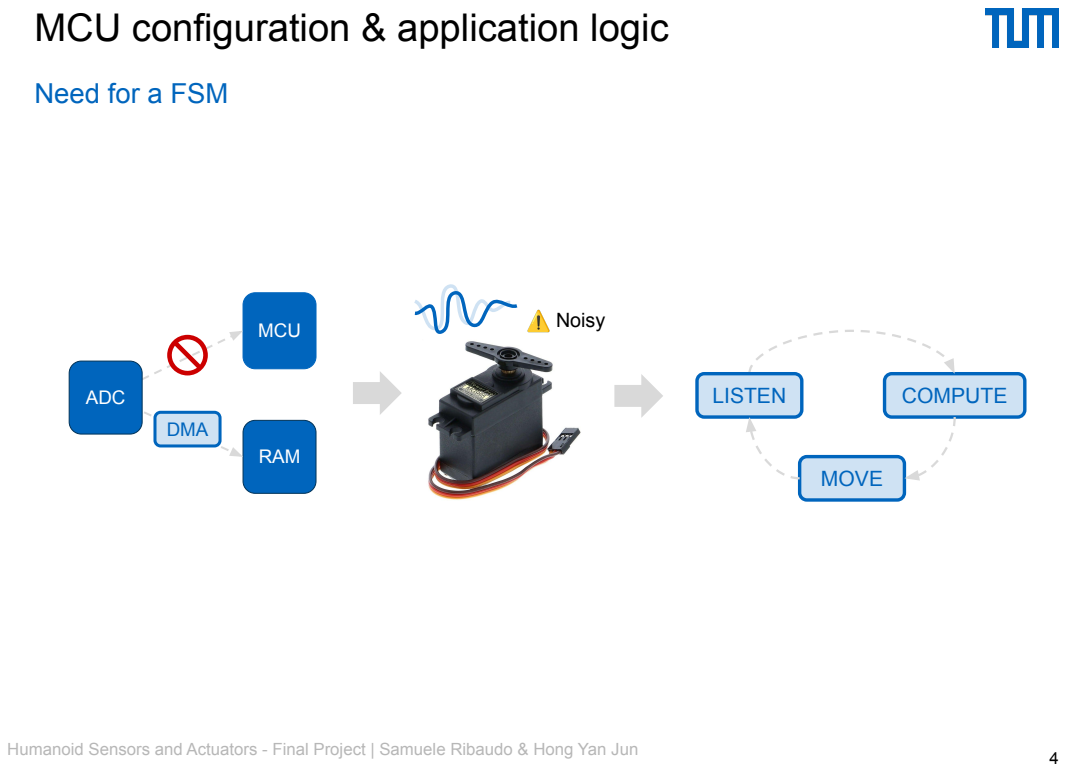
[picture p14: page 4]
Humanoid Sensors and Actuators - Final Project | Samuele Ribaudo & Hong Yan Jun; MCU; RAM; DMA; ADC; COMPUTE; MOVE; LISTEN; Noisy

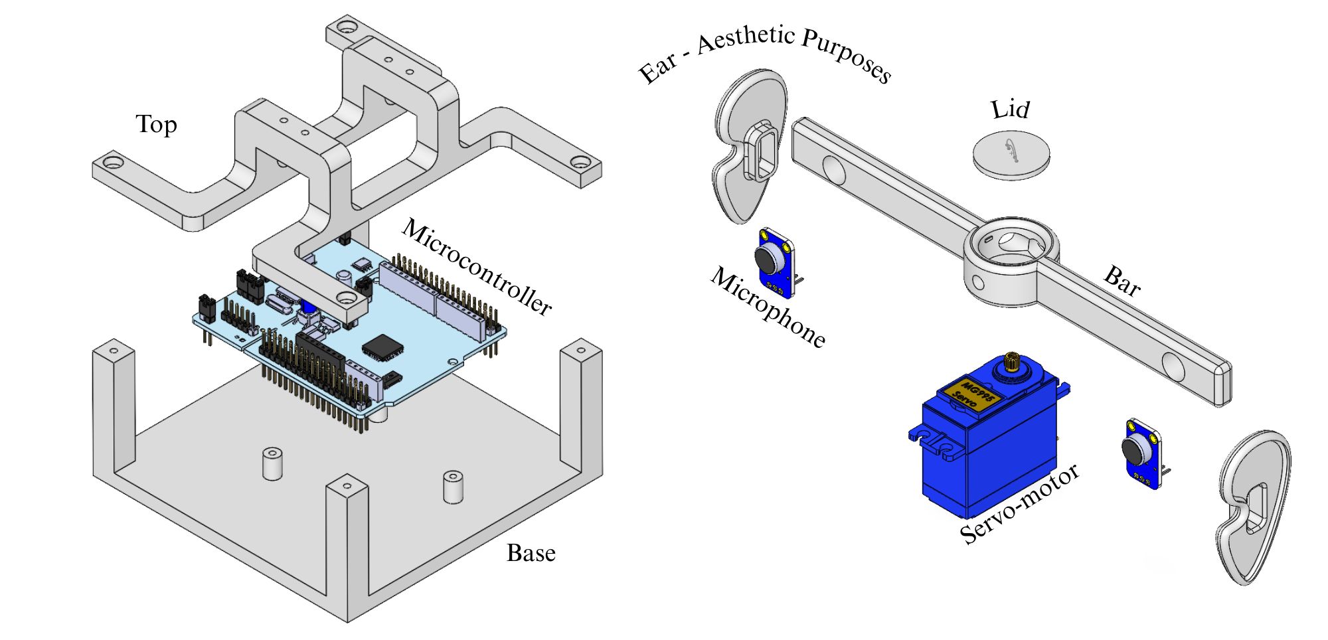
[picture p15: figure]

Humanoid Sensors and Actuators - Final Project | Samuele Ribaudo & Hong Yan Jun | 5

# CAD design & hardware fabrication

## The 3D design

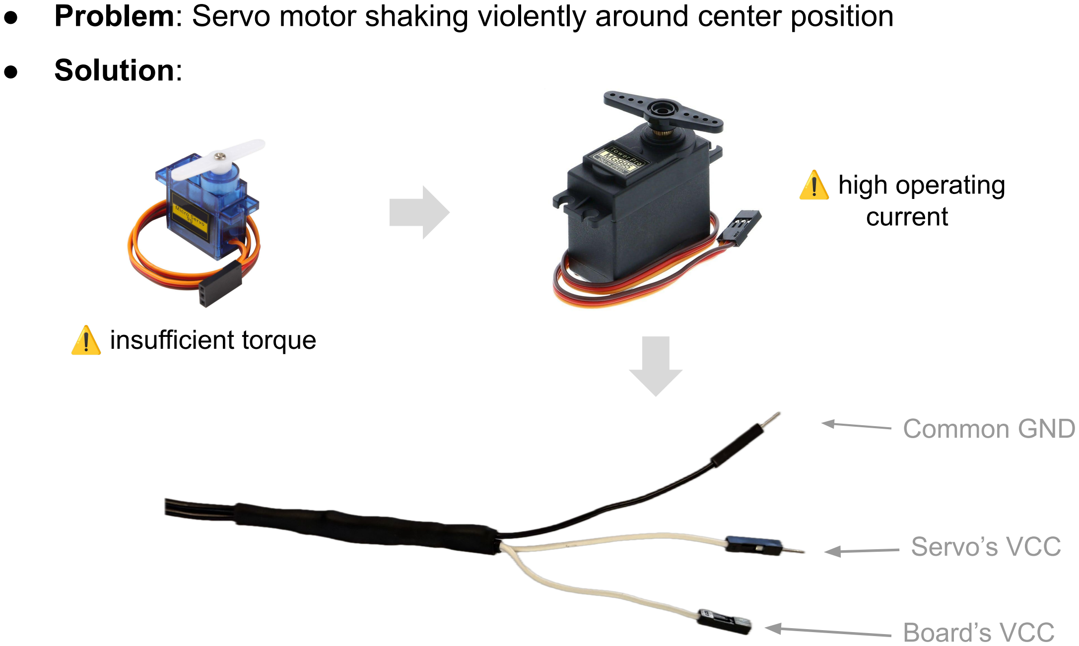
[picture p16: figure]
Common GND; Servo’s VCC; Board’s VCC; ● Solution:; insufficient torque; high operating current

Humanoid Sensors and Actuators - Final Project | Samuele Ribaudo & Hong Yan Jun | 6

# CAD design & hardware fabrication

## - Problem: Servo motor shaking violently around center position

## The servo challenge

## Custom

# DSP pipeline

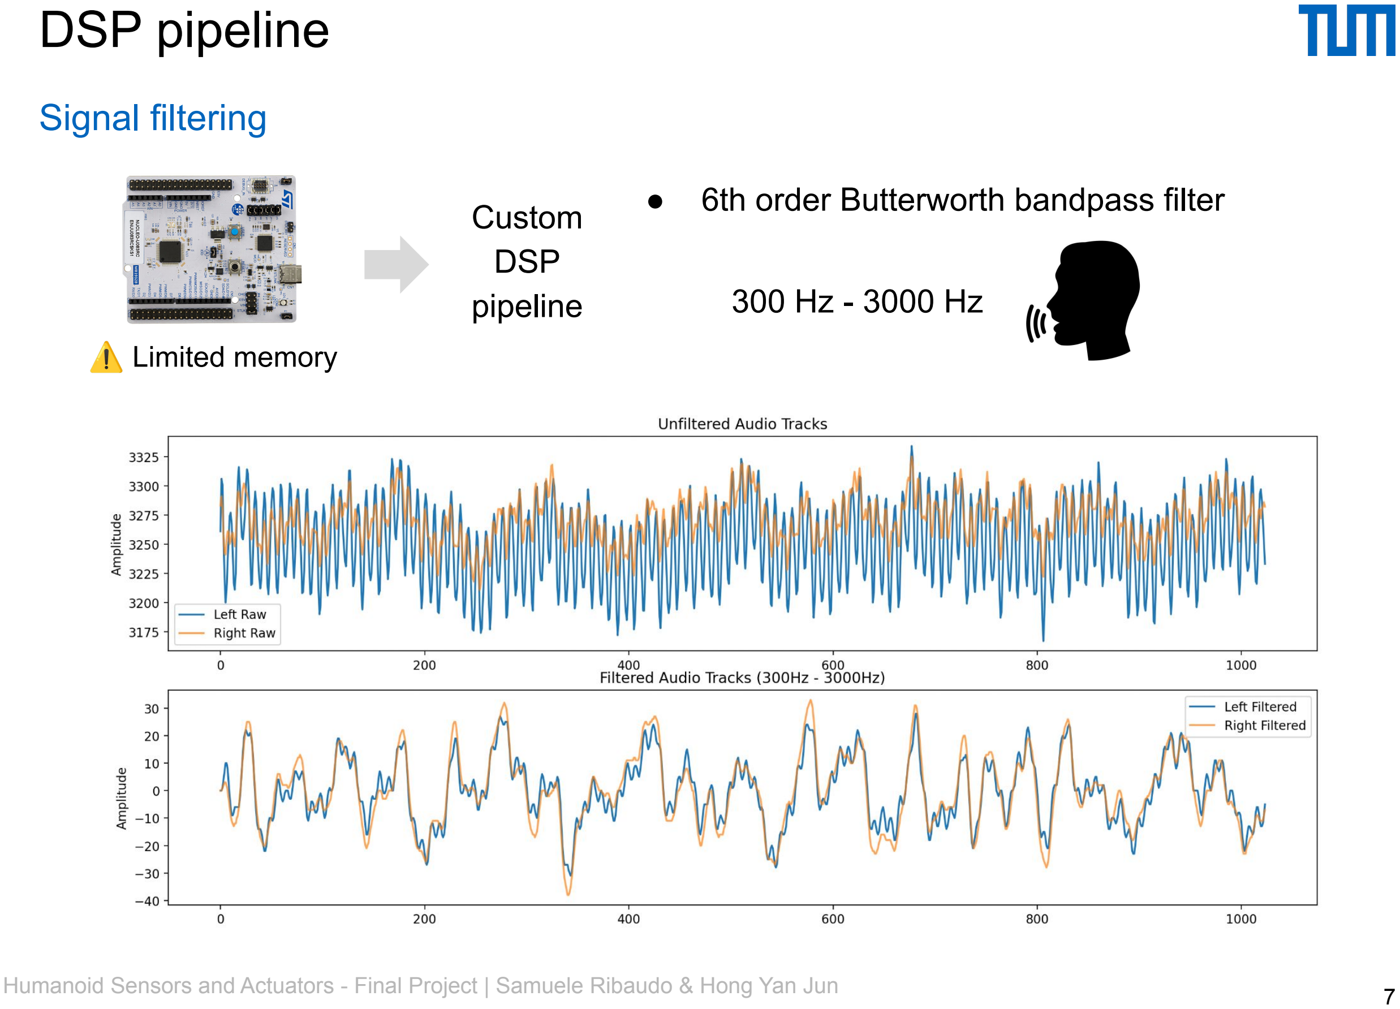
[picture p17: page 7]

## DSP pipeline

## Signal filtering

### Limited memory

## - 6th order Butterworth bandpass filter

## 300 Hz - 3000 Hz

## - To remove the DC offset - Mean-centering

## - To find the Time Delay of Arrival - Cross-correlation

## - Problem: 1024- sample arrays too much for our MCU

## - Solution

## ■ Knowing speed of around and distance between microphone

## ■ Bound search loop to maximum delay of ±22 samples

# DSP pipeline

## Signal processing

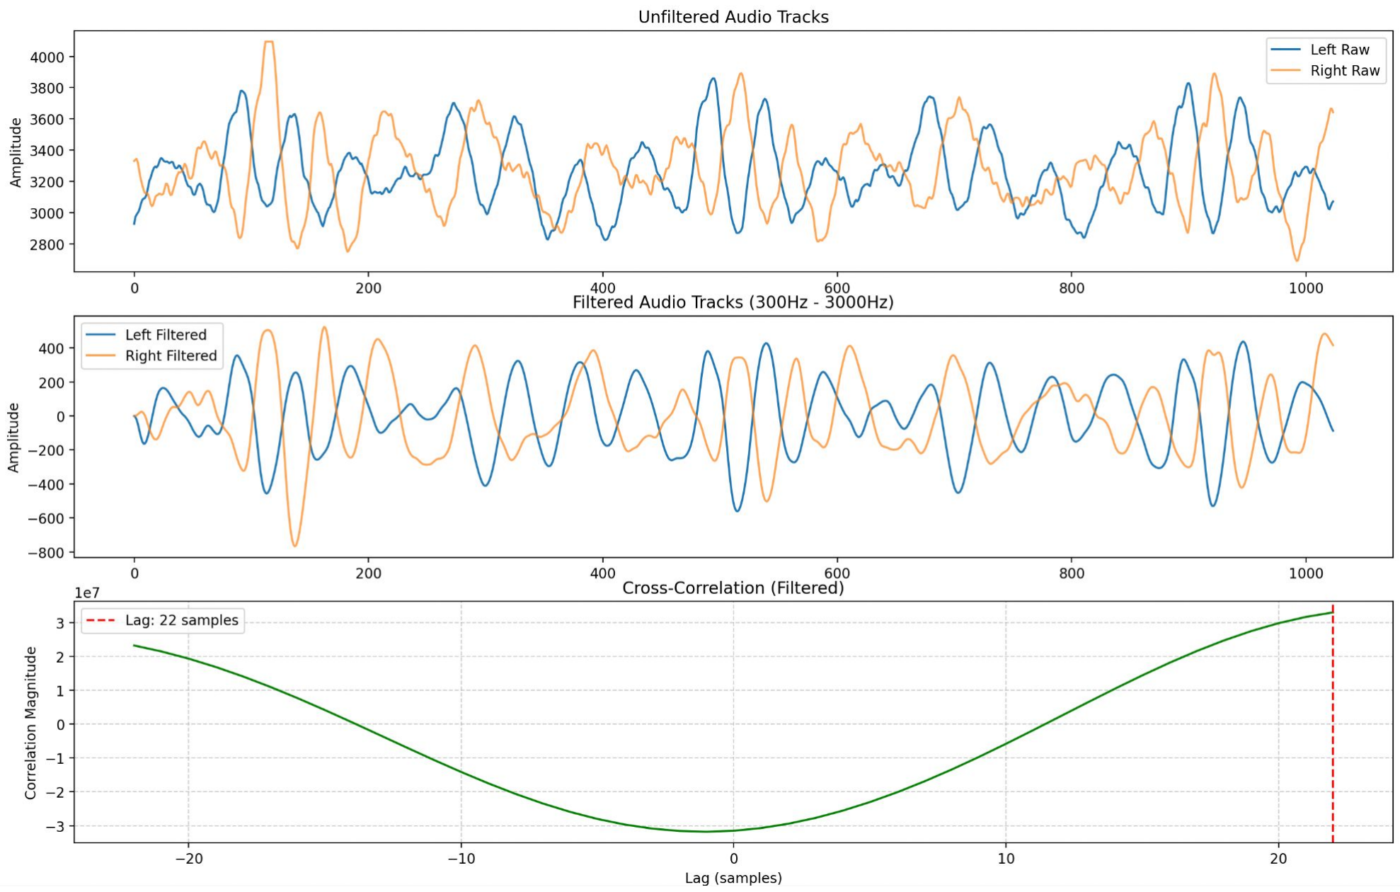
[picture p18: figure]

Humanoid Sensors and Actuators - Final Project | Samuele Ribaudo & Hong Yan Jun | 9

# DSP pipeline

## Signal processing

## Embedded pipeline successfully localizes sound sources in 1D-space in real time, ignoring

noises outside human speech frequencies.

# Conclusions

## QR codes

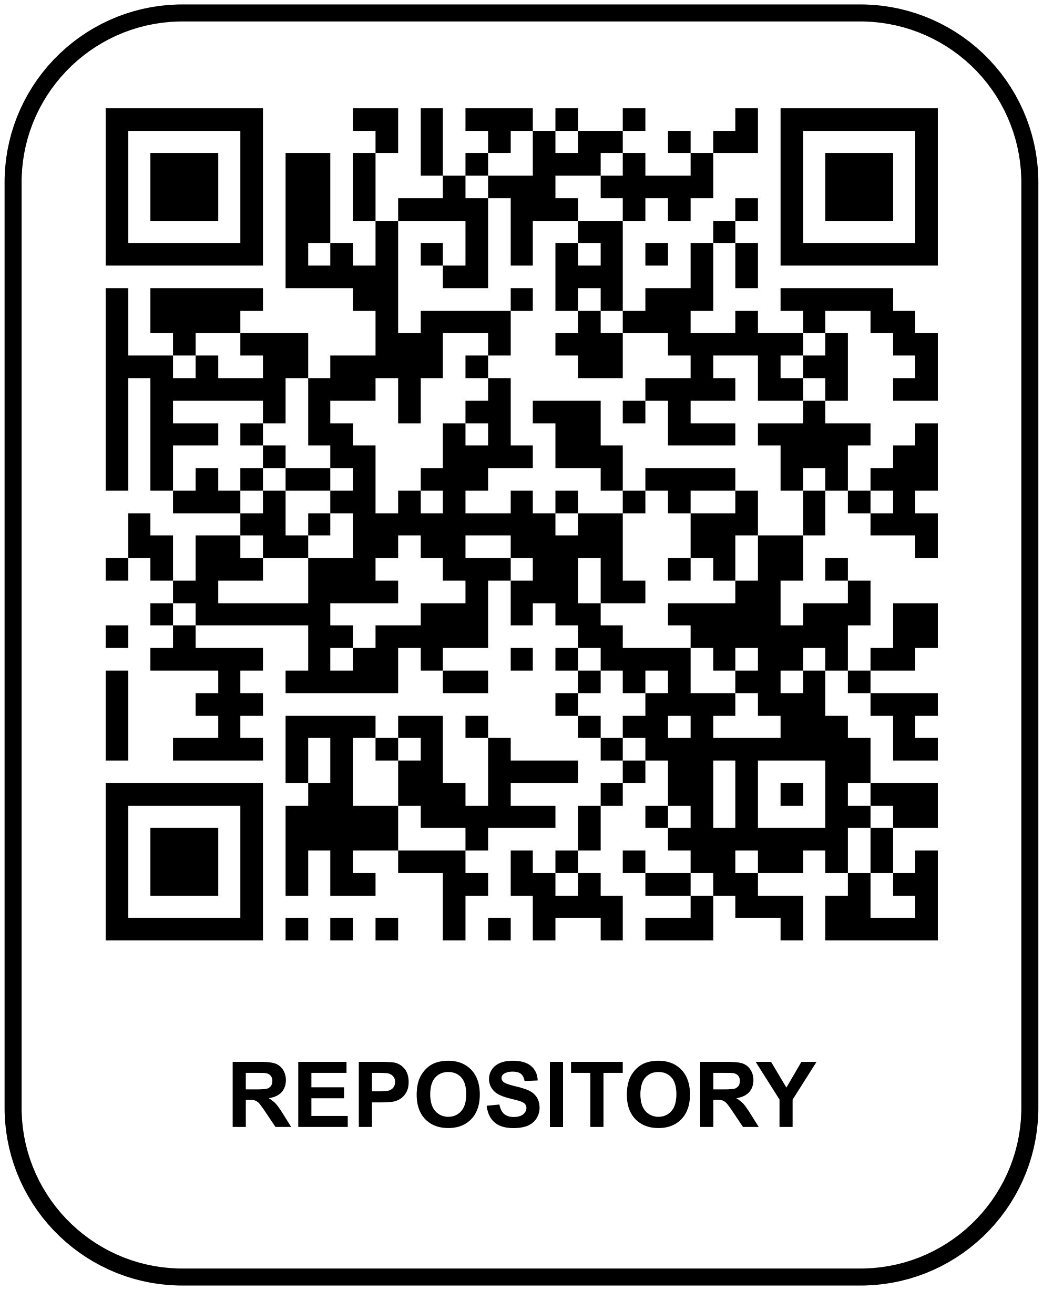
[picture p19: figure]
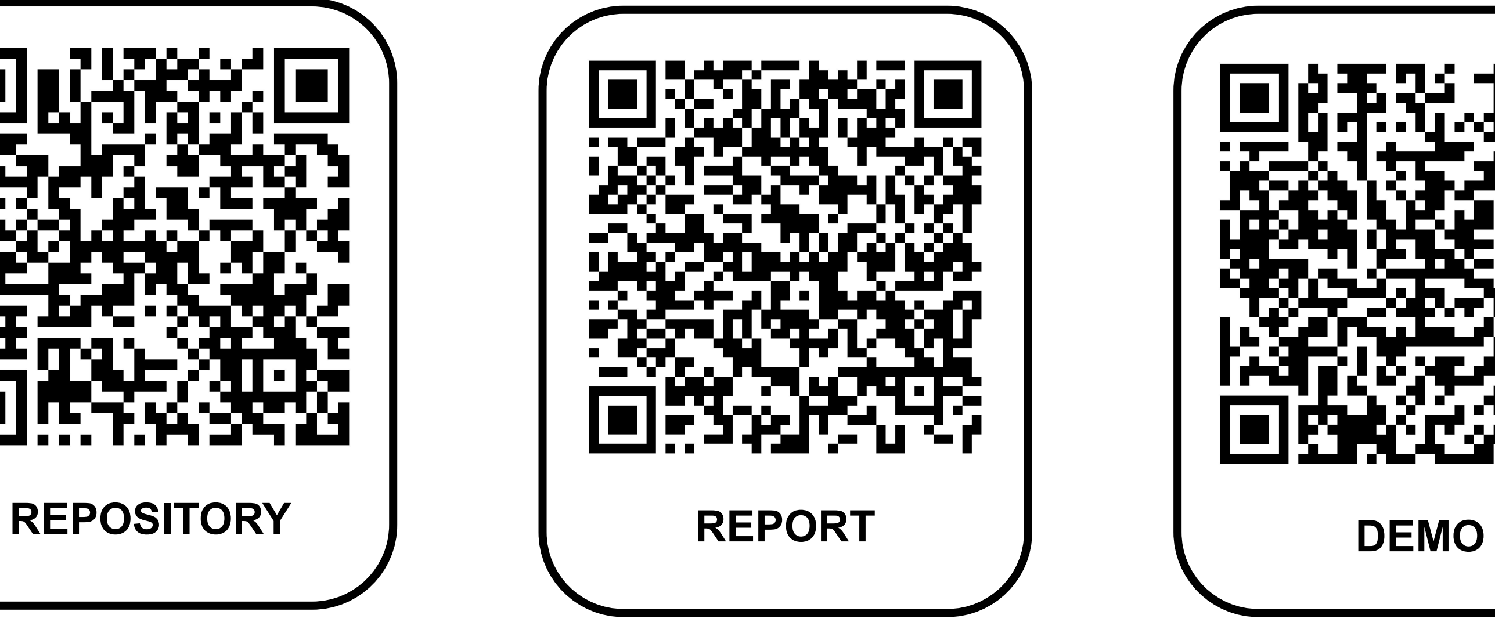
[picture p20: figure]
REPOSITORY; REPORT; DEMO
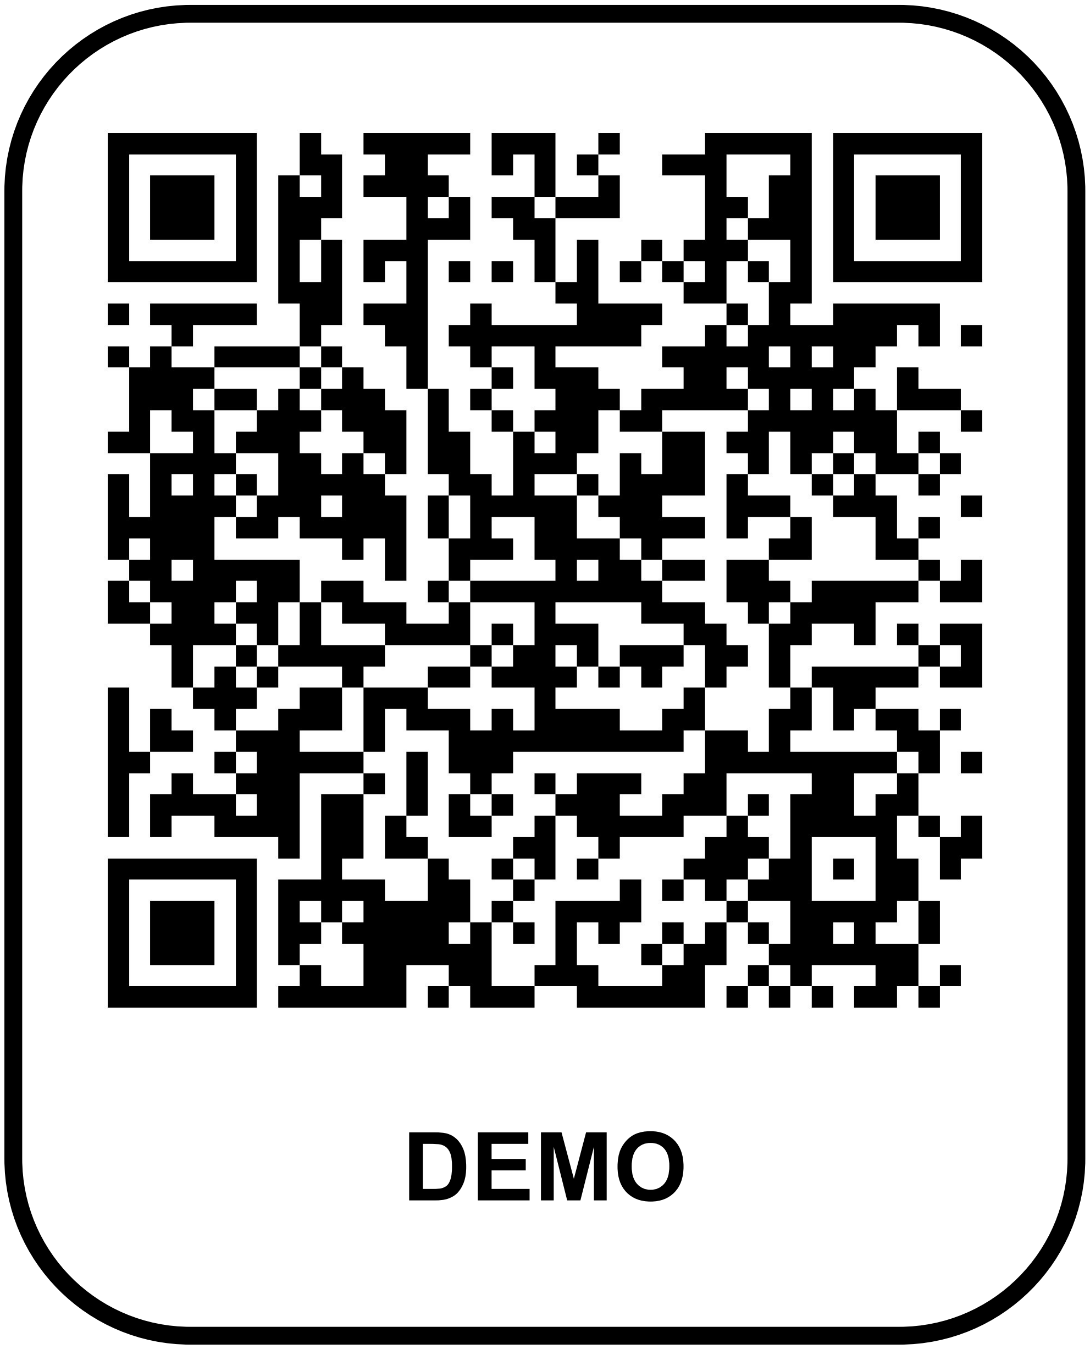
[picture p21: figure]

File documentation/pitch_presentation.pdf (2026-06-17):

# Real-Time Sound Source

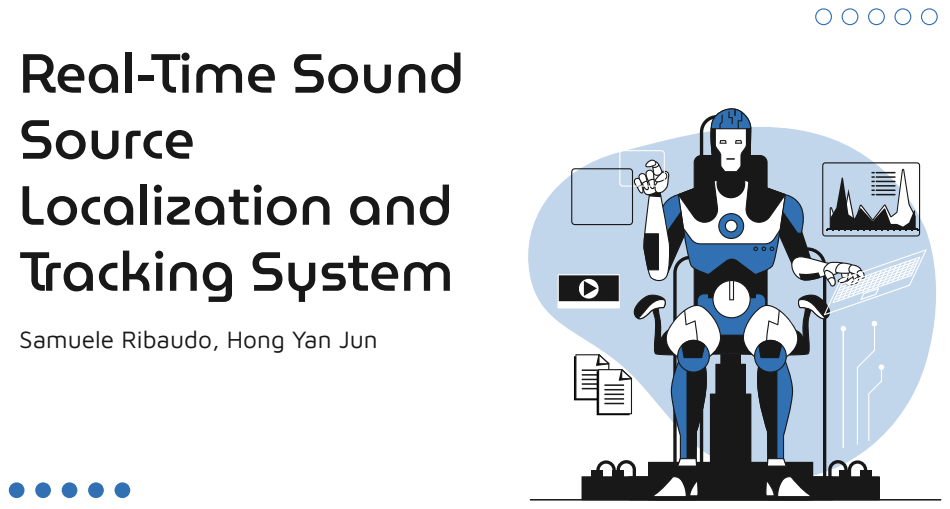
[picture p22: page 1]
Localization and Tracking System

Samuele Ribaudo, Hong Yan Jun

# Project Concept

- Core Idea: Mimicking how human hear sounds
- Using an STM32 microcontroller and two standard microphones, the system acts like a pair of human ears.
- When a person speaks, the system calculates the sound's origin and uses a servo motor to physically rotate the sensor array toward the speaker.

# System Workflow

LISTEN | COMPUTE | ACTUATE
LISTEN | COMPUTE | ACTUATE

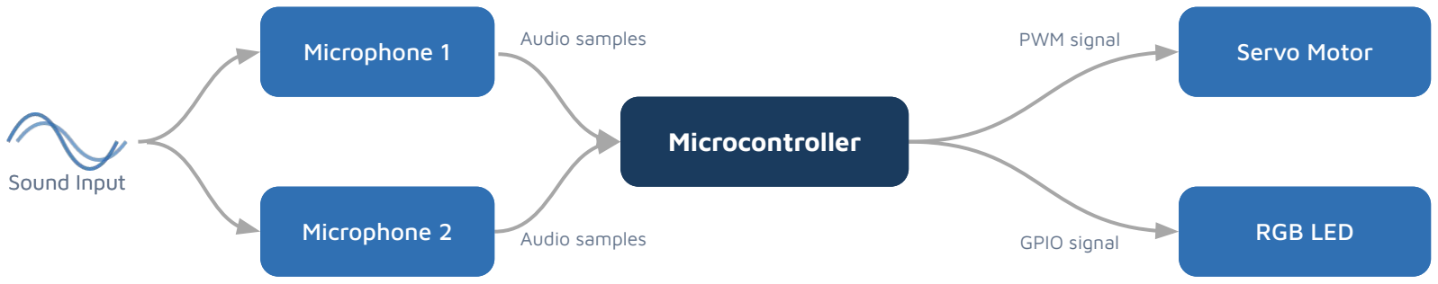
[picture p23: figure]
Sound Input; Microphone 1; Microphone 2; Microcontroller; Servo Motor; RGB LED; Audio samples; PWM signal; GPIO signal

# Technical Details

- Eliminates the acoustic front-back 'cone of confusion' using a physical foam baffle to block rear audio signals.
- Demonstrates architectural depth by implementing the entire signal processing pipeline (filtering & cross-correlation) completely from scratch in standard C.
- "Employs a strict 'Listen-Compute-Move' finite state machine to prevent mechanical servo noise and vibrations from corrupting audio buffers.
- Converts the relative microphone time delays into an absolute coordinate space for precise 180° servo positioning.

# Workload Distribution

Samuele:
1. Peripheral configuration (ADC, DMA, PWM, GPIO, Timers)
2. FSM and application logic
3. Angle computation
4. Actuation

Ryan:
1. CAD design & fabrication
2. Hardware assembly & wiring
3. DSP pipeline (manual)
- Signal filtering
- Cross-correlation & TDOA

# Materials List

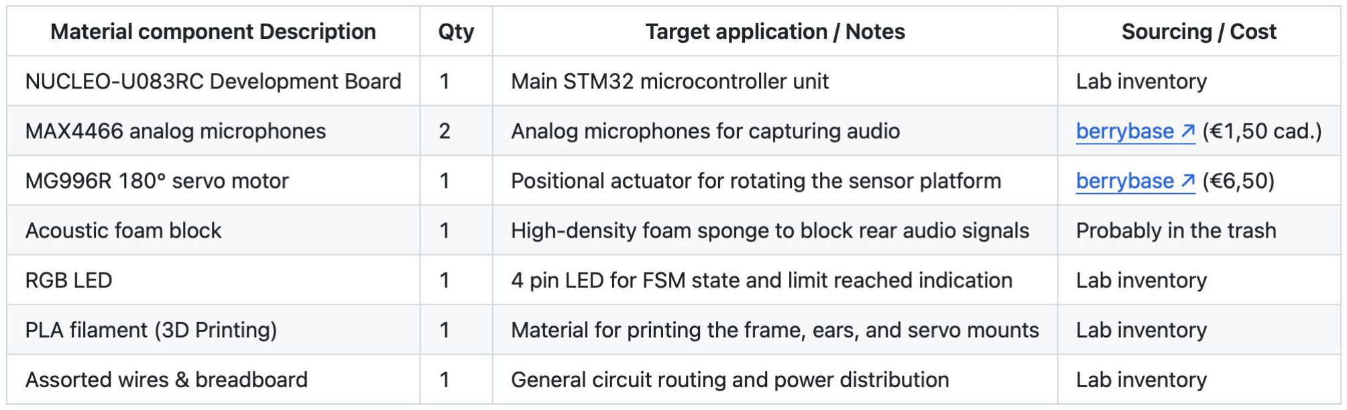
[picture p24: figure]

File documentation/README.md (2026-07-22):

# Academic Documentation

This directory contains the central guidelines, proposals, presentations, and technical reports for the real-time sound source localization and tracking project.

---

### File registry

| File name | Type | Purpose & core contents |
| :--- | :--- | :--- |
| **`project_description.pdf`** | Reference | Official project guidelines, requirements, and grading criteria provided by the instructor at TUM. |
| **`project_proposal.md`** | Specification | Comprehensive proposal detailing system architecture, hardware/software specifications, state machine mechanics, and explicit team workload distribution. |
| **`pitch_presentation.pdf`** | Presentation | Brief pitch presentation deck summarizing the core robotic concept, operational finite state machine workflow, and required materials. |
| **`technical_report.pdf`** | Final deliverable | Core comprehensive engineering and scientific group report developed in strict accordance with the instructor guidelines. |
 **`final_presentation.pdf`** | Presentation | Final presentation of our robotic project. |
| **`demo.mp4`** | Video | The demo video showcasing the core features of the system |

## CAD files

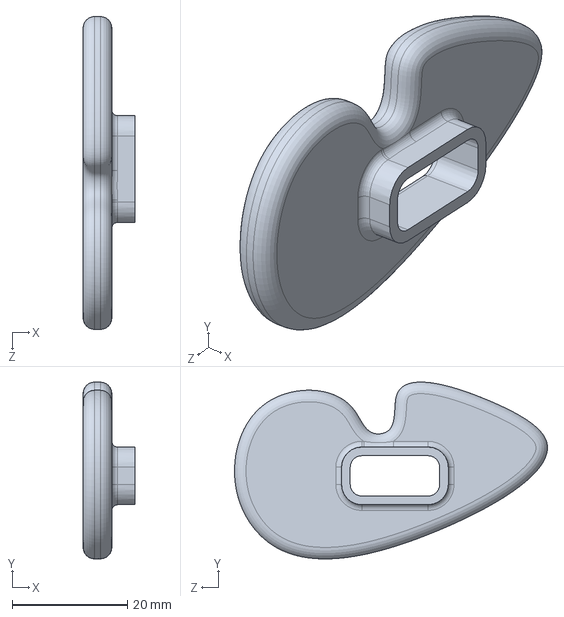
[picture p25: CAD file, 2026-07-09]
hardware/CAD/ears_right.SLDPRT
9.00 x 30.7 x 54.3 mm

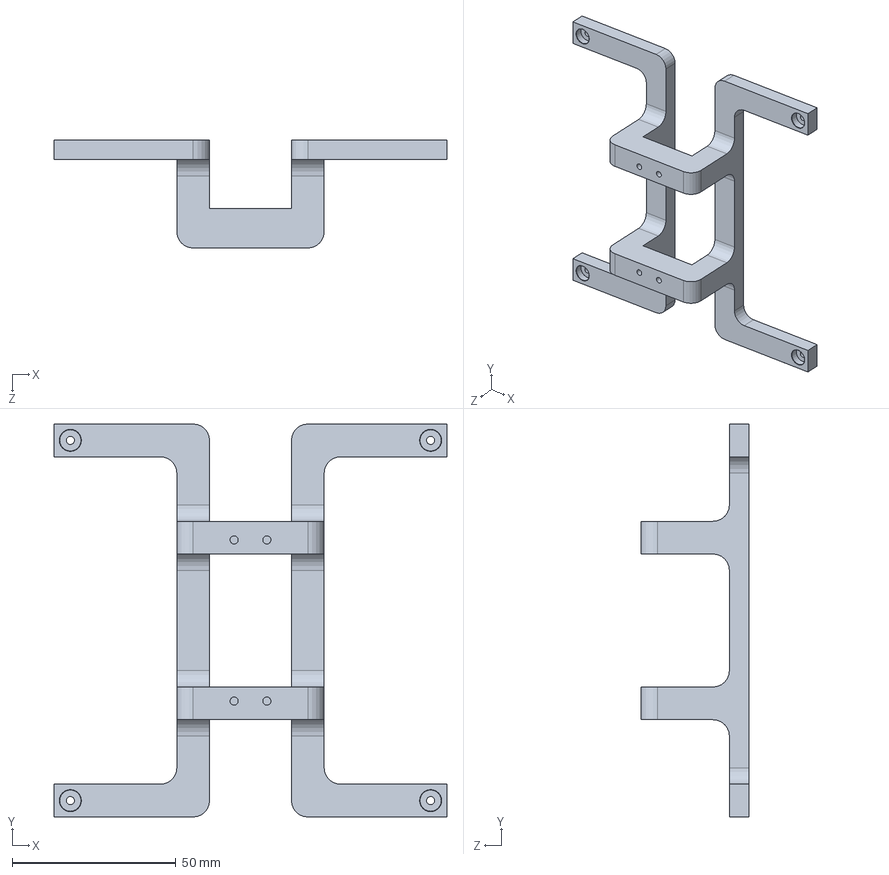
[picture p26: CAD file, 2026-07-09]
hardware/CAD/Top.SLDPRT
120.0 x 120.0 x 33.0 mm

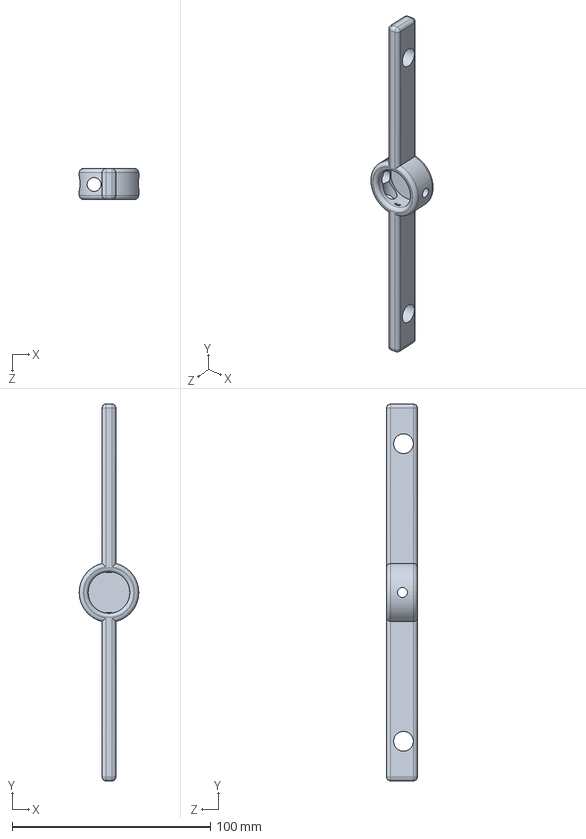
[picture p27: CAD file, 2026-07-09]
hardware/CAD/Bar.SLDPRT
30.0 x 190.0 x 15.5 mm

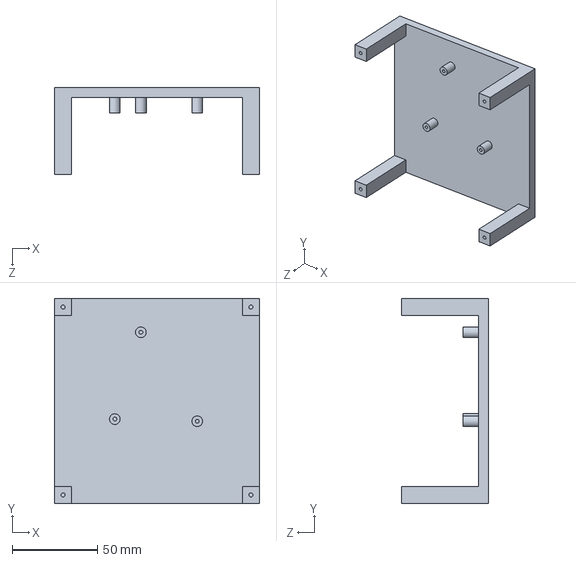
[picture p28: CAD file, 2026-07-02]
hardware/CAD/Base.SLDPRT
120.0 x 120.0 x 51.0 mm

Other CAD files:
hardware/CAD/Final_Assembly.SLDASM
hardware/CAD/ear_left.SLDPRT
hardware/STL/Bar.STL
hardware/STL/Base.STL
hardware/STL/Top.STL
hardware/STL/ear_left.STL
hardware/STL/ears_right.STL

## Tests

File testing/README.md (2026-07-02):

# Testing & Data Collection

This directory contains standalone testing frameworks used to validate our Digital Signal Processing (DSP) algorithms and collect real-world microphone data before deploying the full pipeline to the robot.

---

### Directory structure

#### `dsp_pipeline_test/`
A standalone C test environment used to validate the math behind our filtering and cross-correlation functions without needing to flash the board.
* `dsp_pipeline.c` / `dsp_pipeline.h`: The core algorithm files being tested.
* `main.c`: A test harness that feeds pre-recorded arrays into the DSP functions and stores the processed data in `.csv` files.
* `plot_audio.py`: The python script to plot the processed data.

#### `microphone_data_collector/`
Tools used to capture raw ADC data from the microphones and plot it on a PC. This was vital for characterizing room noise and determining the correct filter thresholds.
* **`main.c`**: A simplified STM32 firmware that reads the ADC and streams the raw values over UART/USB to the PC.
* **`read_microphone_data.py`**: A Python script that listens to the serial port, records the incoming data, and saves it.
* **`data/raw_files/`**: CSV files containing the captured ADC readings for various test scenarios:
  * `sample_0_quiet_room_baseline.csv`: Used to calibrate the amplitude threshold.
  * `sample_1_sound_from_the_right.csv`
  * `sample_2_sound_at_center.csv`
  * `sample_3_sound_from_the_left.csv`
* **`data/images/`**: PNG plots generated from the CSV data, allowing us to visually verify the phase shift between the left and right microphones before implementing cross-correlation in C.

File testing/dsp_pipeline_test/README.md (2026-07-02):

# DSP Pipeline Unit Tests

This directory contains standalone unit tests for the custom digital signal processing pipeline. These tests isolate the hardware-independent algorithmic files (`dsp_pipeline.c` and `dsp_pipeline.h`) from the hardware abstraction layers, enabling rapid simulation and validation on your host computer.

### 1. Directory structure

```text
testing/dsp_pipeline_test/
├── main.c                  # Main test runner
├── dsp_pipeline.h          # Header file defining custom band-pass filters, cross-correlation, and math structures
├── dsp_pipeline.c          # Pure-C manual implementation of DSP algorithms
├── CMakeLists.txt          # Standalone test build configuration for host machine compilation
├── files/                  # Directory containing output and raw data sample files (.csv format)
└── plots/                  # Directory containing some plots we saved from our verification scripts
```

### 2. Prerequisites

Ensure your host environment has the following software installed:
* **Compiler:** `gcc` or `clang` (Natively supported on macOS/Linux)
* **Build System:** `cmake` (version 3.22 or higher) or `make`
* **Python Environments:** `python3` with `matplotlib` and `numpy` installed for plotting scripts.

### 3. Quick start guide

#### Step 1: Build

To build the standalone executable on your host computer, run the following commands from this directory:

```bash
# Create and enter the build directory
mkdir -p build && cd build
# Configure and compile the testing suite
cmake ..
make
```

#### Step 2: Import a raw data file

Save in the directory `files/` a raw data sample file and name it `sample_1_raw.csv`.
For example, you can upload here a file recorded with the microphone data collector framework that are stored inside `testing/microphone_data_collector/data/raw_files`, but remember to rename it.

#### Step 3: Run the c script

Make sure you are in the testing framework directory (`testing/dsp_pipeline_test`) and run:

```bash
./build/dsp_run
```

This executable will ingest your `sample_1_raw.csv`, pass the audio buffers through the discrete band-pass filter (300 Hz - 3000 Hz), compute the cross-correlation function from scratch, and output the results as a new file in the `files/` directory.

#### Step 4: Run the python script

Open your terminal on your PC, navigate to this directory and launch the python script to view the processed data:

```bash
python3 plot_audio.py

```

### 4. How to interpret the data

The output will show 3 images one on top of the other:

1. **The raw signal:** Displays the uncalibrated dual-channel audio data directly imported from your input file, illustrating the ambient background noise and speech ripple before any processing.

2. **The filtered signal:** Shows the waveform after passing through the custom discrete band-pass filter. Frequencies outside human speech parameters (such as low-frequency room hum or high-frequency electrical noise) will be noticeably attenuated.

3. **The cross-correlation:** Plots the cross-correlation function output over the sample lag domain. The highest mathematical peak on this graph explicitly indicates the exact offset between the two microphone elements.

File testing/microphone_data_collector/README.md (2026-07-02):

# Microphone Calibration & Testing Pipeline

This directory provides a quick diagnostic routine to test and validate your dual microphone setup.

### 1. Directory structure

```text
testing/microphone_data_collector
├── data/
│   ├── images/                 # Aligned plots: Raw Waves, Filtered Waves, & Cross-Correlation
│   └── raw_files/              # Raw 12-bit stereo data sheets (.csv) captured from the MCU
├── main.c                      # MCU test firmware (sequences through 4 recording passes)
└── read_microphone_data.py     # Python script to ingest, process, and plot the audio tracks
```

### 2. Quick start guide

#### Step 1: Flash the MCU

Replace your standard `main.c` with the one in this directory, compile, and flash your Nucleo board.
Wait for the LED to turn **RED**.

#### Step 2: Run the python script

Open your terminal on your PC, navigate to this directory and launch the ingestion client:

```bash
python3 read_microphone_data.py
```

*(The script automatically scans for Mac/Linux `/dev/tty.usbmodem*` channels).*

#### Step 3: Run the test sequence

Reset your Nucleo board. The firmware will automatically execute **4 test passes** in this order:

1. **Sample 0**: Keep the room completely quiet (sets the noise baseline).
2. **Sample 1**: Make a sound exclusively from the **right**.
3. **Sample 2**: Make a sound directly in the **center**.
4. **Sample 3**: Make a sound exclusively from the **left**.

**LED Cues per pass**: **Flashing blue** (3-second countdown to prepare your position) $\rightarrow$ **Solid green** (20ms active recording window + 1 second text streaming).
When all 4 steps complete, the board locks on a solid **Red LED**.

### 3. Analytical outputs

Once data collection wraps up, check the `./data/` folders:

* `data/raw_files/`: Contains raw values recorded by the microfon that can be used in the DSP testing framework
* `data/images/`: Contains 3-row diagnostic subplots mapping out the raw waveform, the zero-centered speech-band filtered signals (300 Hz - 3000 Hz), and the cross-correlation curve computed in python.

#### What to check in the Terminal:

* **Right Test**: Should give a **positive lag** value.
* **Center Test**: Should give **exactly 0** (or +-1) sample lag.
* **Left Test**: Should give a **negative sample lag** value.

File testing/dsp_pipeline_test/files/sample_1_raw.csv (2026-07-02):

Left_Channel_Raw | Right_Channel_Raw
3411 | 3568
3445 | 3539
3473 | 3516
3498 | 3508
3508 | 3489
3495 | 3480
3474 | 3477
3459 | 3476
3454 | 3480
3462 | 3472
3449 | 3449
3447 | 3424
3449 | 3419
3451 | 3424
3450 | 3426
3437 | 3415
3414 | 3379
3408 | 3334
3415 | 3291
3423 | 3252
3421 | 3218
3403 | 3191
3375 | 3169
3349 | 3157
3331 | 3148
3323 | 3121
3312 | 3083
3312 | 3040
3320 | 3007
3335 | 2997
3349 | 3003
3347 | 3000
3335 | 2992
3329 | 2975
3330 | 2960
3338 | 2937
3333 | 2912
3328 | 2896
3317 | 2896
3307 | 2909
3304 | 2924
3289 | 2919
3277 | 2899
3273 | 2879
3281 | 2875
3293 | 2896
3289 | 2925
3259 | 2955
3229 | 2993
3209 | 3033
3197 | 3073
3194 | 3103
3188 | 3115
3179 | 3140
3176 | 3178
3173 | 3233
3160 | 3285
3136 | 3312
3114 | 3321
3112 | 3323
3123 | 3325
3131 | 3326
3125 | 3326
3104 | 3327
3084 | 3344
3076 | 3363
3075 | 3373
3070 | 3363
3067 | 3339
3079 | 3325
3100 | 3327
3122 | 3344
3121 | 3345
3116 | 3334
3121 | 3318
3142 | 3295
3172 | 3268
3196 | 3223
3212 | 3179
3219 | 3152
3232 | 3152
3243 | 3164
3246 | 3163
3243 | 3138
3242 | 3103
3263 | 3074
3288 | 3067
3303 | 3064
3302 | 3062
3287 | 3077
3280 | 3096
3276 | 3115
3281 | 3126
3283 | 3120
3271 | 3115
3268 | 3134
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

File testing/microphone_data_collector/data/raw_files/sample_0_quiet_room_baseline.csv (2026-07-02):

Left_Channel_Raw | Right_Channel_Raw
3261 | 3283
3306 | 3291
3301 | 3281
3257 | 3257
3221 | 3242
3200 | 3241
3210 | 3253
3235 | 3261
3253 | 3261
3274 | 3250
3277 | 3253
3267 | 3258
3243 | 3260
3217 | 3252
3211 | 3248
3225 | 3258
3270 | 3280
3303 | 3295
3316 | 3295
3300 | 3287
3275 | 3282
3256 | 3285
3254 | 3298
3263 | 3302
3277 | 3299
3301 | 3295
3314 | 3293
3310 | 3289
3287 | 3284
3245 | 3266
3215 | 3254
3216 | 3255
3245 | 3266
3281 | 3280
3295 | 3274
3286 | 3259
3262 | 3248
3237 | 3249
3221 | 3250
3212 | 3249
3219 | 3242
3247 | 3249
3278 | 3260
3294 | 3270
3284 | 3262
3245 | 3248
3215 | 3233
3207 | 3243
3227 | 3261
3258 | 3275
3285 | 3280
3298 | 3272
3295 | 3272
3275 | 3270
3242 | 3261
3213 | 3252
3208 | 3241
3227 | 3250
3269 | 3271
3301 | 3281
3297 | 3273
3271 | 3260
3243 | 3253
3223 | 3250
3222 | 3265
3237 | 3269
3255 | 3266
3282 | 3269
3302 | 3275
3297 | 3282
3269 | 3280
3238 | 3265
3221 | 3265
3235 | 3276
3269 | 3287
3291 | 3289
3297 | 3282
3283 | 3264
3261 | 3255
3239 | 3257
3208 | 3253
3209 | 3249
3227 | 3253
3261 | 3265
3293 | 3272
3297 | 3277
3271 | 3260
3232 | 3248
3207 | 3242
3208 | 3251
3227 | 3263
3248 | 3262
3271 | 3261
3278 | 3260
3277 | 3261
3247 | 3253
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

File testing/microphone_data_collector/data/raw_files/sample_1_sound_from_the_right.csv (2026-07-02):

Left_Channel_Raw | Right_Channel_Raw
2928 | 3331
2971 | 3338
2986 | 3344
2998 | 3323
3010 | 3282
3035 | 3237
3063 | 3202
3082 | 3173
3089 | 3146
3092 | 3127
3105 | 3121
3129 | 3124
3169 | 3113
3206 | 3088
3222 | 3056
3249 | 3041
3271 | 3047
3288 | 3071
3295 | 3099
3289 | 3109
3298 | 3112
3315 | 3120
3339 | 3120
3349 | 3116
3344 | 3115
3333 | 3123
3327 | 3153
3325 | 3184
3327 | 3184
3322 | 3167
3316 | 3130
3321 | 3112
3324 | 3114
3322 | 3139
3301 | 3163
3286 | 3189
3283 | 3224
3288 | 3242
3301 | 3259
3299 | 3257
3284 | 3260
3272 | 3266
3254 | 3291
3235 | 3312
3208 | 3303
3187 | 3280
3171 | 3243
3166 | 3221
3163 | 3217
3147 | 3220
3121 | 3238
3113 | 3280
3118 | 3330
3142 | 3381
3168 | 3412
3179 | 3418
3185 | 3410
3177 | 3415
3163 | 3440
3138 | 3454
3102 | 3456
3070 | 3444
3052 | 3421
3051 | 3394
3047 | 3376
3046 | 3356
3027 | 3344
3009 | 3353
3003 | 3376
3011 | 3391
3039 | 3387
3061 | 3358
3096 | 3328
3151 | 3301
3214 | 3299
3266 | 3304
3315 | 3301
3356 | 3289
3408 | 3271
3469 | 3235
3526 | 3185
3568 | 3125
3588 | 3071
3604 | 3036
3621 | 3027
3630 | 3017
3640 | 2982
3644 | 2931
3675 | 2882
3712 | 2845
3753 | 2836
3780 | 2841
3780 | 2864
3773 | 2915
3766 | 2979
3751 | 3061
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

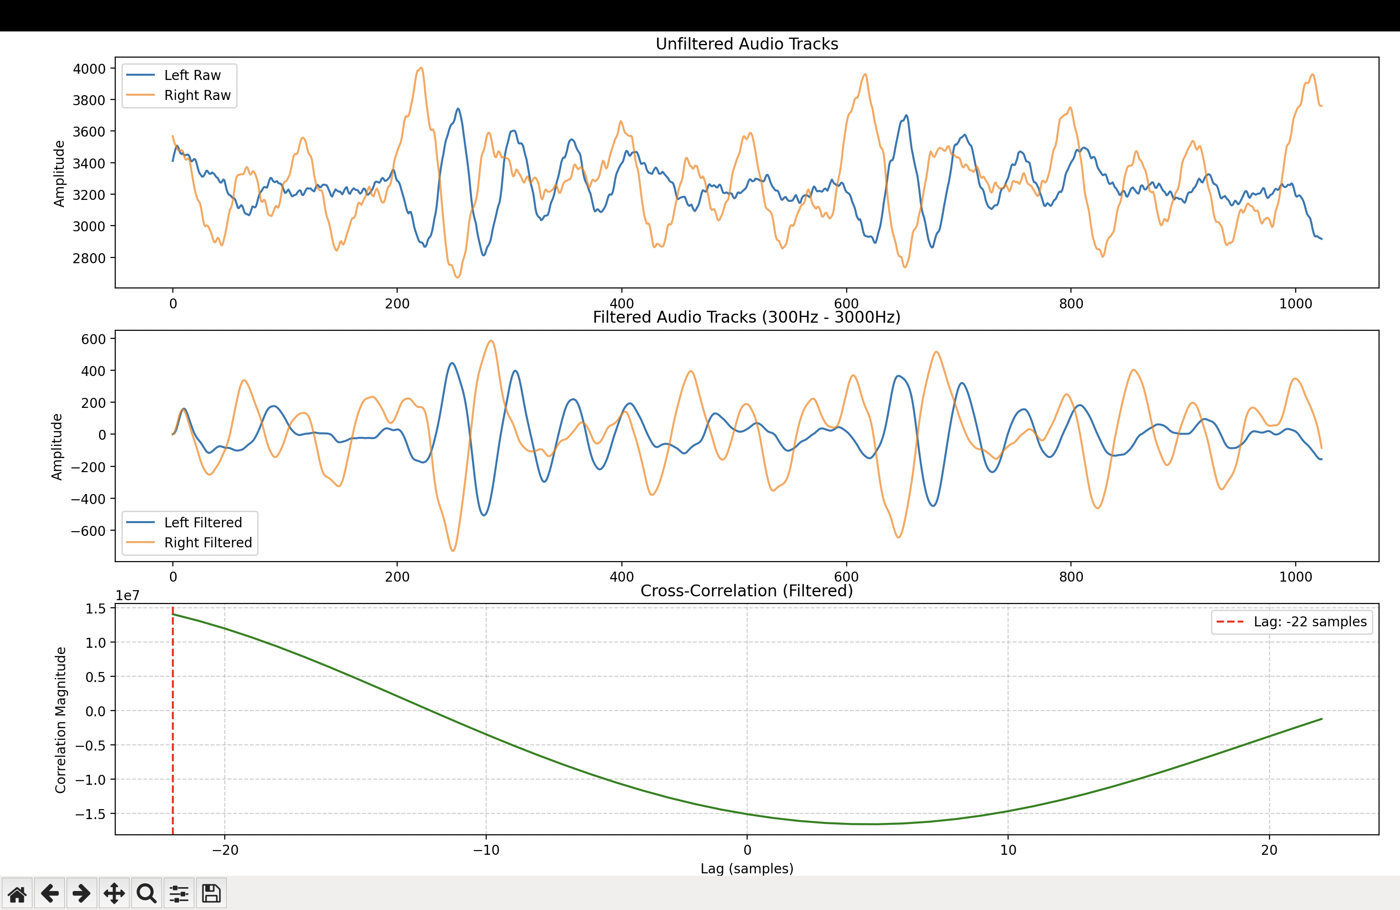
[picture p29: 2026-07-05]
testing/dsp_pipeline_test/plots/final_analysis/left.png

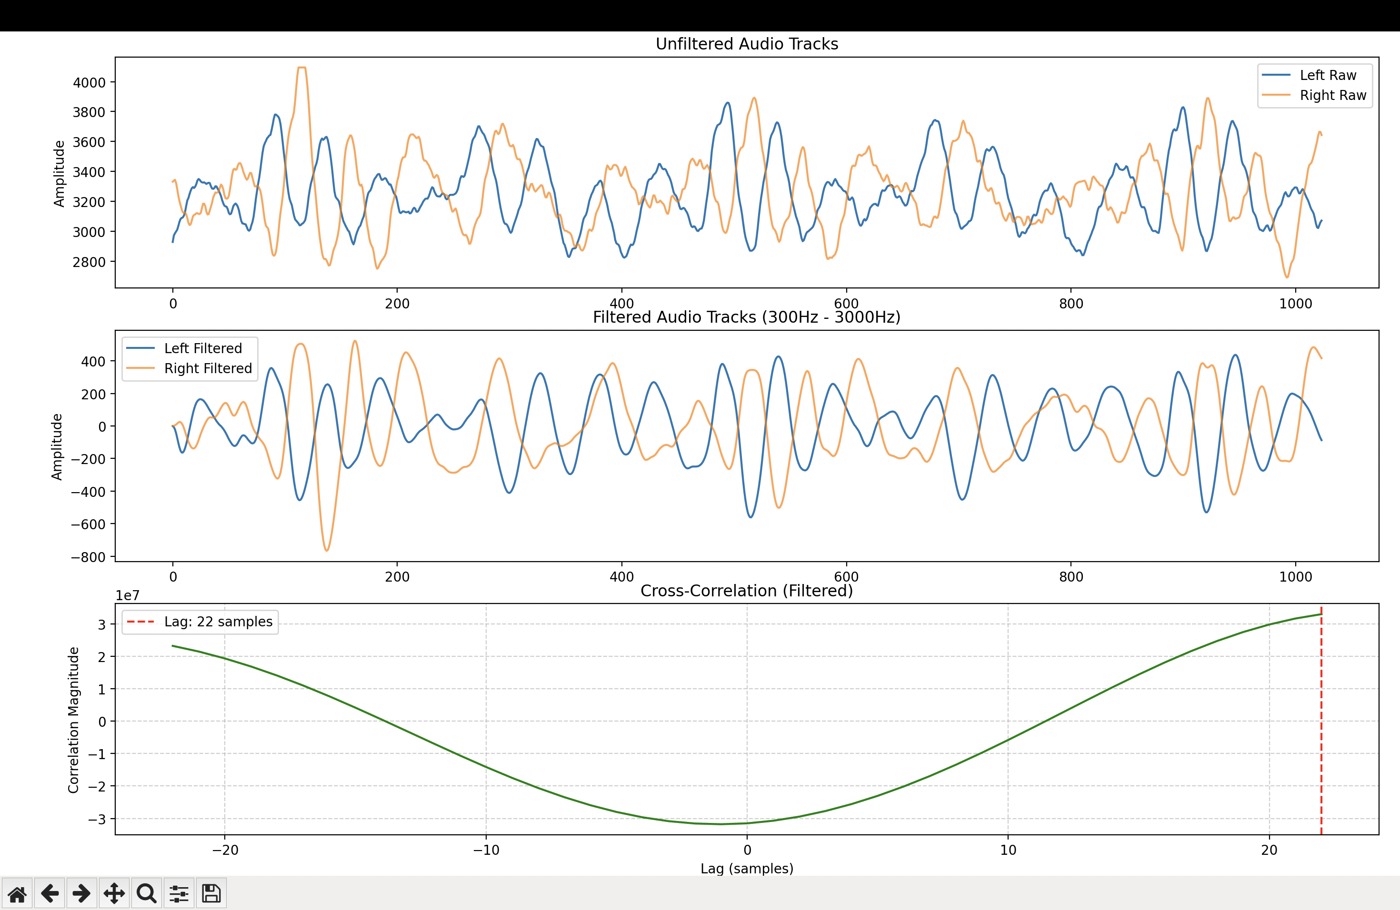
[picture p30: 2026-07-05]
testing/dsp_pipeline_test/plots/final_analysis/right.png

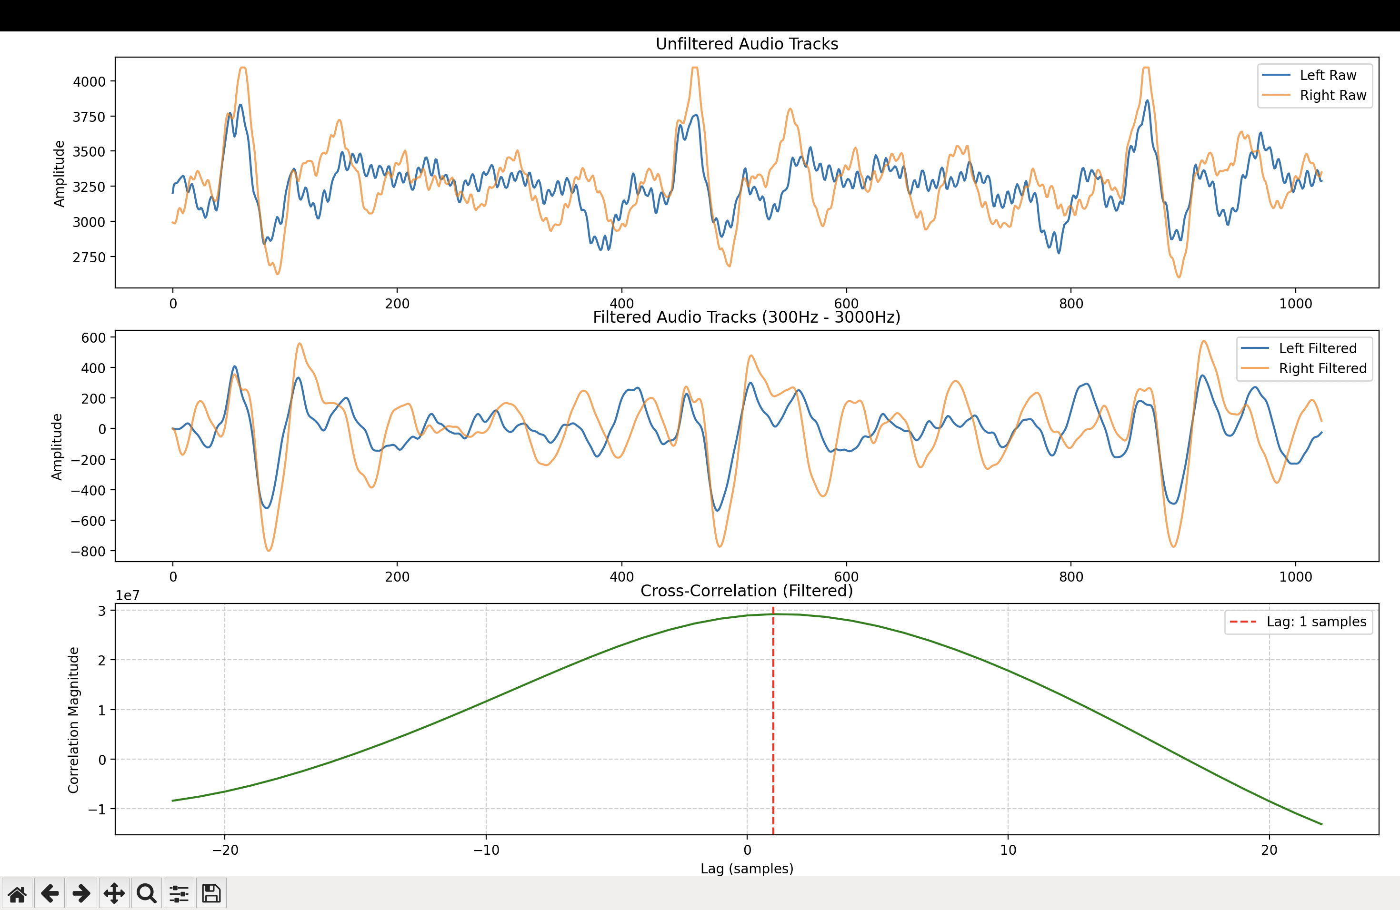
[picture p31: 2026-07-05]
testing/dsp_pipeline_test/plots/final_analysis/center.png

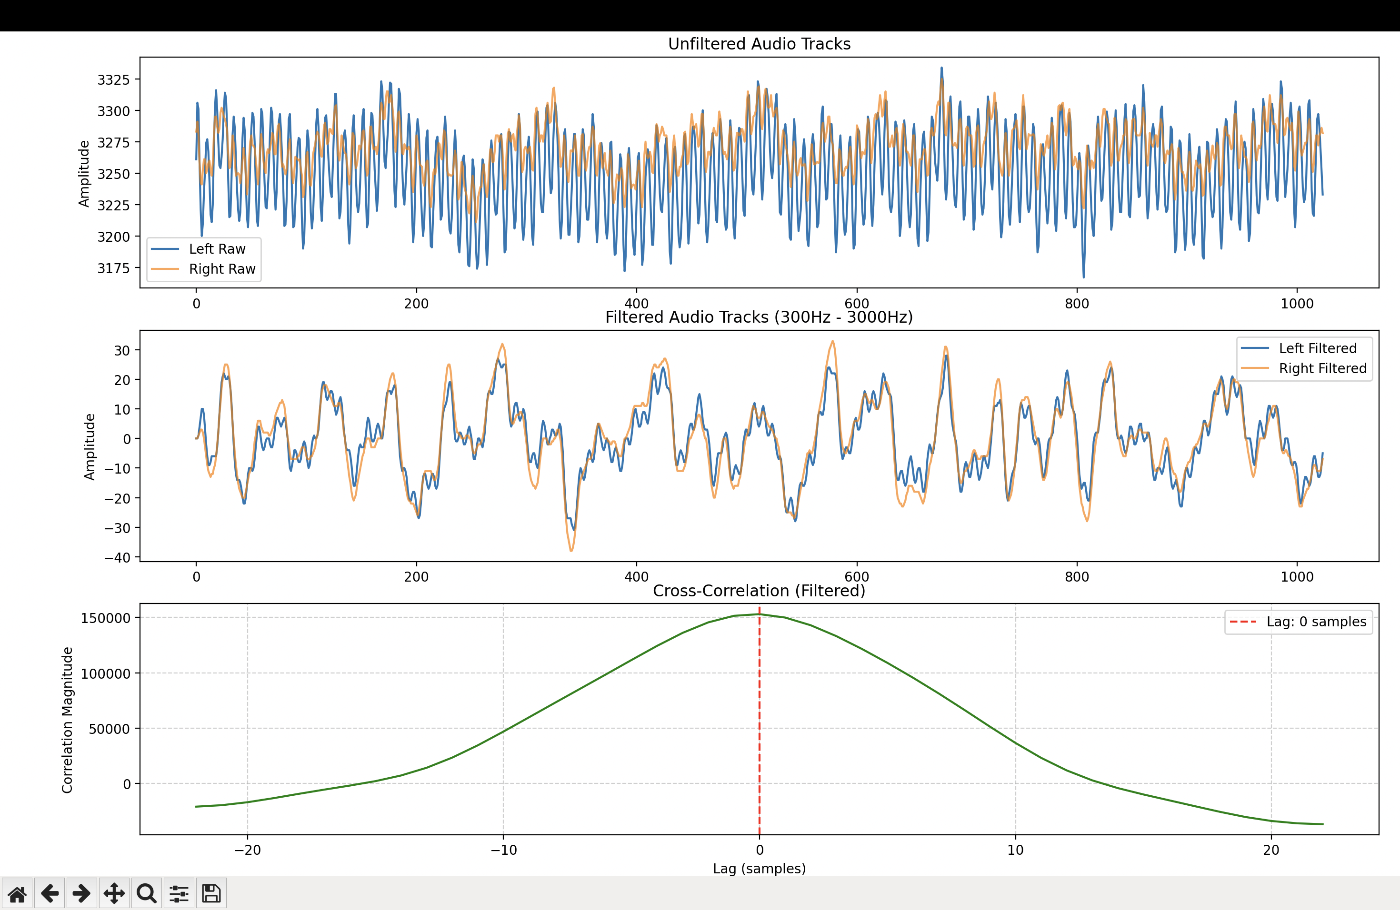
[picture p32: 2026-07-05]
testing/dsp_pipeline_test/plots/final_analysis/baseline.png

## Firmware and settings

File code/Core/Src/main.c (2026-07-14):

/**
 * @file    main.c
 * @brief   Main application logic and finite state machine (FSM) controller.
 *
 * @details This file serves as the primary entry point for the Real-Time Sound 
 * Source Localization and Tracking System. Its main structure consists of 
 * hardware peripheral initialization (ADC, DMA, Timers, GPIO) and a 
 * sequential Finite State Machine (Listen, Compute, Actuate, Settle, 
 * Out-of-Bounds). It bridges the DSP algorithm outputs with physical 
 * motor actuation while preventing mechanical servo noise from 
 * interfering with microphone recordings.
 */

#include "main.h"
#include "cmsis_gcc.h"
#include "config.h"
#include "dsp_pipeline.h"
#include "stm32u0xx_hal.h"
#include "stm32u0xx_hal_adc.h"
#include "stm32u0xx_hal_gpio.h"
#include "stm32u0xx_hal_tim.h"
#include <stdbool.h>
#include <stdint.h>
#include <math.h>

/* Private defines -----------------------------------------------------------*/
typedef enum {
    STATE_LISTEN,
    STATE_COMPUTE,
    STATE_ACTUATE,
    STATE_SETTLE,
    STATE_OUT_OF_BOUNDS
} system_state_t;

typedef enum {
    RED,
    GREEN,
    BLUE,
    OFF
} led_state_t;


/* Setup variables -----------------------------------------------------------*/
COM_InitTypeDef BspCOMInit;
ADC_HandleTypeDef hadc1;
DMA_HandleTypeDef hdma_adc1;
TIM_HandleTypeDef htim2;
TIM_HandleTypeDef htim3;


/* Function prototypes -------------------------------------------------------*/
static void stm32cubeMX_setup(void);
static void set_led_state(led_state_t color);
static void split_raw_data(void);
static float compute_angle_offset(int16_t sample_offset);
static float set_servo_angle(float target_angle, float current_angle);


/* Variables -----------------------------------------------------------------*/
// global state machine tracker
volatile system_state_t system_state = STATE_LISTEN;
volatile bool out_of_bound_detected = false;

// audio buffers
uint16_t adc_dma_buffer[TOTAL_DMA_BUFFER_SIZE];
uint16_t left_channel_buffer[AUDIO_BUFFER_SIZE];
uint16_t right_channel_buffer[AUDIO_BUFFER_SIZE];



/* ============================== MAIN LOOP ================================= */

int main(void)
{
  // variables
  float current_servo_angle = SERVO_CENTER_ANGLE; // Start at center
  float target_servo_angle = SERVO_CENTER_ANGLE; // Start at center
  float angle_offset;
  int16_t sample_offset;
  uint32_t last_sound_time = HAL_GetTick(); // for inactivity timeout

  // wrapper function to hide stm32cubeMX generated code from the main function
  stm32cubeMX_setup();

  // Turn on the Servo PWM Timer (Timer 2)
  HAL_TIM_PWM_Start(&htim2, TIM_CHANNEL_1);

  // Turn on the ADC Trigger Timer (Timer 3)
  HAL_TIM_Base_Start(&htim3);

  current_servo_angle = set_servo_angle(SERVO_CENTER_ANGLE, current_servo_angle); // Center the servo at startup
  HAL_Delay(BEAM_SETUP_DELAY); // Allow time for the servo to reach center position and center the beam

  while (1){
    switch(system_state){

      case STATE_LISTEN:

            set_led_state(BLUE);

            // Start the DMA transferl
            HAL_ADC_Start_DMA(&hadc1, (uint32_t*)adc_dma_buffer, TOTAL_DMA_BUFFER_SIZE);

            // Sleep CPU until DMA interrupt wakes it up and changes state to COMPUTE
            while(system_state == STATE_LISTEN) __WFI();
            break;


      case STATE_COMPUTE:

            set_led_state(BLUE);

            // Split the raw interleaved DMA data into clean left/right channels
            split_raw_data();
            
            // Call DSP pipeline and check if a sound was detected
            if(!DSP_pipeline(&sample_offset, QUIET_ROOM_TRESHOLD , left_channel_buffer, right_channel_buffer, AUDIO_BUFFER_SIZE, MAX_SAMPLE_LAG)){
              
              // If no sound detected, check for inactivity timeout
              if((HAL_GetTick() - last_sound_time > INACTIVITY_TIMEOUT) && (fabs(current_servo_angle - SERVO_CENTER_ANGLE) > 0.01f)){
                target_servo_angle = SERVO_CENTER_ANGLE; // Set angle to center
                last_sound_time = HAL_GetTick(); // Reset the timer so it doesn't constantly trigger
                system_state = STATE_ACTUATE;    // Go to actuate state to move the motor
              }
              else system_state = STATE_LISTEN;     // Otherwise, keep listening
              break; 
            }

            last_sound_time = HAL_GetTick(); // Update the sound tracker if a sound was detected

            // Compute the angle offset
            angle_offset = compute_angle_offset(sample_offset);

            // Set the new servo angle and check for boundary conditions
            if(current_servo_angle + angle_offset > SERVO_MAX_ANGLE){
              target_servo_angle = SERVO_MAX_ANGLE;
              out_of_bound_detected = true;
            }
            else if(current_servo_angle + angle_offset < SERVO_MIN_ANGLE){
              target_servo_angle = SERVO_MIN_ANGLE;
              out_of_bound_detected = true;
            } 
            else target_servo_angle += angle_offset;

            // go to next state
            system_state = STATE_ACTUATE;
            break;


      case STATE_ACTUATE:

            set_led_state(GREEN);
            
            // update servo position
            current_servo_angle = set_servo_angle(target_servo_angle, current_servo_angle);

            // change state
            if(out_of_bound_detected) system_state = STATE_OUT_OF_BOUNDS;
            else system_state = STATE_SETTLE;
            break;


      case STATE_SETTLE:

            // delay for servo mechanical noise
            set_led_state(GREEN);
            HAL_Delay(SETTLING_TIME);

            system_state = STATE_LISTEN;
            break;


      case STATE_OUT_OF_BOUNDS:

            // reset out of bound flag
            out_of_bound_detected = false;
            // Flash Red LED for OUT_OF_BOUNDS_DELAY
            int count = OUT_OF_BOUNDS_DELAY / 500;
            if(count < 1) count = 1; // Ensure at least one flash
            for(int i = 0; i < count; i++){
              set_led_state(RED);
              HAL_Delay(250);
              set_led_state(OFF);
              HAL_Delay(250);
            }
            // change state
            system_state = STATE_LISTEN;
            break;
    }
  }
}



/* ============================== FUNCTIONS ================================== */

/**
* @brief change the RGB LED state
* @param[in] color the desired color [RED, GREEN, BLUE] or [OFF] to turn it off
* @retval none
*/
static void set_led_state(led_state_t color){
  switch(color){
    case RED:
      HAL_GPIO_WritePin(LED_R_GPIO_Port, LED_R_Pin, GPIO_PIN_SET);
      HAL_GPIO_WritePin(LED_G_GPIO_Port, LED_G_Pin, GPIO_PIN_RESET);
      HAL_GPIO_WritePin(LED_B_GPIO_Port, LED_B_Pin, GPIO_PIN_RESET);
      break;
    
    case GREEN:
      HAL_GPIO_WritePin(LED_R_GPIO_Port, LED_R_Pin, GPIO_PIN_RESET);
      HAL_GPIO_WritePin(LED_G_GPIO_Port, LED_G_Pin, GPIO_PIN_SET);
      HAL_GPIO_WritePin(LED_B_GPIO_Port, LED_B_Pin, GPIO_PIN_RESET);
      break;

    case BLUE:
      HAL_GPIO_WritePin(LED_R_GPIO_Port, LED_R_Pin, GPIO_PIN_RESET);
      HAL_GPIO_WritePin(LED_G_GPIO_Port, LED_G_Pin, GPIO_PIN_RESET);
      HAL_GPIO_WritePin(LED_B_GPIO_Port, LED_B_Pin, GPIO_PIN_SET);
      break;

    case OFF:
      HAL_GPIO_WritePin(LED_R_GPIO_Port, LED_R_Pin, GPIO_PIN_RESET);
      HAL_GPIO_WritePin(LED_G_GPIO_Port, LED_G_Pin, GPIO_PIN_RESET);
      HAL_GPIO_WritePin(LED_B_GPIO_Port, LED_B_Pin, GPIO_PIN_RESET);
      break;
  }
}


/**
* @brief split the raw data collected by the ADC into a left and right channel buffers
* @retval none
*/
static void split_raw_data(void){

  for(uint16_t i = 0; i < AUDIO_BUFFER_SIZE; i++) {
    left_channel_buffer[i]  = adc_dma_buffer[2 * i];
    right_channel_buffer[i] = adc_dma_buffer[2 * i + 1];
  }
}


/**
* @brief compute the angle offset of the sound source based on the number of sample
*        offset between the two channels
* @param[in] sample_offset the offset between the two channels recordings
* @retval angle offset in radiants 
*/
static float compute_angle_offset(int16_t sample_offset){

  // compute the time delay of arrival
  float TDOA = (float) sample_offset / SAMPLE_FREQUENCY_HZ;

  // compute the angle offset applying the formula seen in the lectures
  float asin_arg = TDOA * SPEED_OF_SOUND / MIC_DISTANCE;

  // clamp the computer value for safety
  if(asin_arg > 1.0f) asin_arg = 1.0f;
  else if(asin_arg < -1.0f) asin_arg = -1.0f;

  float angle_offset = asinf(asin_arg);

  return angle_offset;
}


/**
* @brief set the servo motor to the desired angle within the servo limitations at a controlled speed
* @param[in] target_angle the desired target angle in radians
* @param[in] current_angle the current angle of the servo in radians
* @retval the updated current servo angle in radians
*/
static float set_servo_angle(float target_angle, float current_angle){

  if(SERVO_SPEED < 1.0f && SERVO_SPEED > 0.0f){ // Only limit the speed if it's between 0 and 1
    float step = 0.0952f * SERVO_SPEED; // 0.0952 rad per 10ms = 0.11 sec / 60 degrees
    while(fabsf(target_angle - current_angle) > step){
      current_angle += (target_angle > current_angle) ? step : -step;

      int pwm_value = current_angle * (SERVO_MAX_PWM - SERVO_MIN_PWM)/(SERVO_MAX_ANGLE - SERVO_MIN_ANGLE) + SERVO_MIN_PWM;
      if(pwm_value > SERVO_MAX_PWM) pwm_value = SERVO_MAX_PWM;
      else if(pwm_value < SERVO_MIN_PWM) pwm_value = SERVO_MIN_PWM;
      __HAL_TIM_SET_COMPARE(&htim2, TIM_CHANNEL_1, pwm_value);
      HAL_Delay(10);
    }
  }

  // Set final target position
  int pwm_value = target_angle * (SERVO_MAX_PWM - SERVO_MIN_PWM)/(SERVO_MAX_ANGLE - SERVO_MIN_ANGLE) + SERVO_MIN_PWM;
  if(pwm_value > SERVO_MAX_PWM) pwm_value = SERVO_MAX_PWM;
  else if(pwm_value < SERVO_MIN_PWM) pwm_value = SERVO_MIN_PWM;
  __HAL_TIM_SET_COMPARE(&htim2, TIM_CHANNEL_1, pwm_value);
  return target_angle; // Return the final angle for tracking
}



/* ============================== INTERRUPT CALLBACKS ======================== */

/**
* @brief Conversion complete ISR invoked automatically when the ADC DMA buffer is completely filled with audio samples.
* @param[in, out] hadc Pointer to the ADC handle structure
* @retval none
*/
void HAL_ADC_ConvCpltCallback(ADC_HandleTypeDef *hadc){
  if(hadc->Instance == ADC1){
    // stop the ADC
    HAL_ADC_Stop_DMA(hadc);
    // update FSM state to COMPUTE
    system_state = STATE_COMPUTE;
  } 
}



/* ============================== HARDWARE SETUP ============================= */

void SystemClock_Config(void);
static void MX_GPIO_Init(void);
static void MX_DMA_Init(void);
static void MX_TIM2_Init(void);
static void MX_ADC1_Init(void);
static void MX_TIM3_Init(void);

/**
  * @brief wrapper function to hide stm32cubeMX generated code from the main function
  * @return None
  */
static void stm32cubeMX_setup(void)
{
  HAL_Init();
  /* Configure the system clock */
  SystemClock_Config();
  /* Initialize all configured peripherals */
  MX_GPIO_Init();
  MX_DMA_Init();
  MX_TIM2_Init();
  MX_ADC1_Init();
  MX_TIM3_Init();
  /* Initialize USER push-button, will be used to trigger an interrupt each time it's pressed.*/
  BSP_PB_Init(BUTTON_USER, BUTTON_MODE_EXTI);
  /* Initialize COM1 port (115200, 8 bits (7-bit data + 1 stop bit), no parity */
  BspCOMInit.BaudRate   = 115200;
  BspCOMInit.WordLength = COM_WORDLENGTH_8B;
  BspCOMInit.StopBits   = COM_STOPBITS_1;
  BspCOMInit.Parity     = COM_PARITY_NONE;
  BspCOMInit.HwFlowCtl  = COM_HWCONTROL_NONE;
  if (BSP_COM_Init(COM1, &BspCOMInit) != BSP_ERROR_NONE)
  {
    Error_Handler();
  }
}

/**
  * @brief System Clock Configuration
  * @retval None
  */
void SystemClock_Config(void)
{
  RCC_OscInitTypeDef RCC_OscInitStruct = {0};
  RCC_ClkInitTypeDef RCC_ClkInitStruct = {0};

  /** Configure the main internal regulator output voltage
  */
  HAL_PWREx_ControlVoltageScaling(PWR_REGULATOR_VOLTAGE_SCALE2);

  /** Initializes the RCC Oscillators according to the specified parameters
  * in the RCC_OscInitTypeDef structure.
  */
  RCC_OscInitStruct.OscillatorType = RCC_OSCILLATORTYPE_HSI;
  RCC_OscInitStruct.HSIState = RCC_HSI_ON;
  RCC_OscInitStruct.HSICalibrationValue = RCC_HSICALIBRATION_DEFAULT;
  RCC_OscInitStruct.PLL.PLLState = RCC_PLL_NONE;
  if (HAL_RCC_OscConfig(&RCC_OscInitStruct) != HAL_OK)
  {
    Error_Handler();
  }

  /** Initializes the CPU, AHB and APB buses clocks
  */
  RCC_ClkInitStruct.ClockType = RCC_CLOCKTYPE_HCLK|RCC_CLOCKTYPE_SYSCLK
                              |RCC_CLOCKTYPE_PCLK1;
  RCC_ClkInitStruct.SYSCLKSource = RCC_SYSCLKSOURCE_HSI;
  RCC_ClkInitStruct.AHBCLKDivider = RCC_SYSCLK_DIV1;
  RCC_ClkInitStruct.APB1CLKDivider = RCC_HCLK_DIV1;

  if (HAL_RCC_ClockConfig(&RCC_ClkInitStruct, FLASH_LATENCY_1) != HAL_OK)
  {
    Error_Handler();
  }
}

/**
  * @brief ADC1 Initialization Function
  * @param None
  * @retval None
  */
static void MX_ADC1_Init(void)
{
  ADC_ChannelConfTypeDef sConfig = {0};

  /** Configure the global features of the ADC (Clock, Resolution, Data Alignment and number of conversion)
  */
  hadc1.Instance = ADC1;
  hadc1.Init.ClockPrescaler = ADC_CLOCK_SYNC_PCLK_DIV1;
  hadc1.Init.Resolution = ADC_RESOLUTION_12B;
  hadc1.Init.DataAlign = ADC_DATAALIGN_RIGHT;
  hadc1.Init.ScanConvMode = ADC_SCAN_ENABLE;
  hadc1.Init.EOCSelection = ADC_EOC_SINGLE_CONV;
  hadc1.Init.LowPowerAutoWait = DISABLE;
  hadc1.Init.LowPowerAutoPowerOff = DISABLE;
  hadc1.Init.ContinuousConvMode = DISABLE;
  hadc1.Init.NbrOfConversion = 2;
  hadc1.Init.DiscontinuousConvMode = DISABLE;
  hadc1.Init.ExternalTrigConv = ADC_EXTERNALTRIG_T3_TRGO;
  hadc1.Init.ExternalTrigConvEdge = ADC_EXTERNALTRIGCONVEDGE_RISING;
  hadc1.Init.DMAContinuousRequests = ENABLE;
  hadc1.Init.Overrun = ADC_OVR_DATA_PRESERVED;
  hadc1.Init.SamplingTimeCommon1 = ADC_SAMPLETIME_1CYCLE_5;
  hadc1.Init.SamplingTimeCommon2 = ADC_SAMPLETIME_1CYCLE_5;
  hadc1.Init.OversamplingMode = DISABLE;
  hadc1.Init.TriggerFrequencyMode = ADC_TRIGGER_FREQ_HIGH;
  if (HAL_ADC_Init(&hadc1) != HAL_OK)
  {
    Error_Handler();
  }

  /** Configure Regular Channel
  */
  sConfig.Channel = ADC_CHANNEL_0;
  sConfig.Rank = ADC_REGULAR_RANK_1;
  sConfig.SamplingTime = ADC_SAMPLINGTIME_COMMON_1;
  if (HAL_ADC_ConfigChannel(&hadc1, &sConfig) != HAL_OK)
  {
    Error_Handler();
  }

  /** Configure Regular Channel
  */
  sConfig.Channel = ADC_CHANNEL_1;
  sConfig.Rank = ADC_REGULAR_RANK_2;
  if (HAL_ADC_ConfigChannel(&hadc1, &sConfig) != HAL_OK)
  {
    Error_Handler();
  }
}

/**
  * @brief TIM2 Initialization Function
  * @param None
  * @retval None
  */
static void MX_TIM2_Init(void)
{

  TIM_ClockConfigTypeDef sClockSourceConfig = {0};
  TIM_MasterConfigTypeDef sMasterConfig = {0};
  TIM_OC_InitTypeDef sConfigOC = {0};

  htim2.Instance = TIM2;
  htim2.Init.Prescaler = 15;
  htim2.Init.CounterMode = TIM_COUNTERMODE_UP;
  htim2.Init.Period = 19999;
  htim2.Init.ClockDivision = TIM_CLOCKDIVISION_DIV1;
  htim2.Init.AutoReloadPreload = TIM_AUTORELOAD_PRELOAD_ENABLE;
  if (HAL_TIM_Base_Init(&htim2) != HAL_OK)
  {
    Error_Handler();
  }
  sClockSourceConfig.ClockSource = TIM_CLOCKSOURCE_INTERNAL;
  if (HAL_TIM_ConfigClockSource(&htim2, &sClockSourceConfig) != HAL_OK)
  {
    Error_Handler();
  }
  if (HAL_TIM_PWM_Init(&htim2) != HAL_OK)
  {
    Error_Handler();
  }
  sMasterConfig.MasterOutputTrigger = TIM_TRGO_RESET;
  sMasterConfig.MasterSlaveMode = TIM_MASTERSLAVEMODE_DISABLE;
  if (HAL_TIMEx_MasterConfigSynchronization(&htim2, &sMasterConfig) != HAL_OK)
  {
    Error_Handler();
  }
  sConfigOC.OCMode = TIM_OCMODE_PWM1;
  sConfigOC.Pulse = 1500;
  sConfigOC.OCPolarity = TIM_OCPOLARITY_HIGH;
  sConfigOC.OCFastMode = TIM_OCFAST_DISABLE;
  if (HAL_TIM_PWM_ConfigChannel(&htim2, &sConfigOC, TIM_CHANNEL_1) != HAL_OK)
  {
    Error_Handler();
  }
  HAL_TIM_MspPostInit(&htim2);

}

/**
  * @brief TIM3 Initialization Function
  * @param None
  * @retval None
  */
static void MX_TIM3_Init(void)
{

  TIM_ClockConfigTypeDef sClockSourceConfig = {0};
  TIM_MasterConfigTypeDef sMasterConfig = {0};

  htim3.Instance = TIM3;
  htim3.Init.Prescaler = 0;
  htim3.Init.CounterMode = TIM_COUNTERMODE_UP;
  htim3.Init.Period = 319;
  htim3.Init.ClockDivision = TIM_CLOCKDIVISION_DIV1;
  htim3.Init.AutoReloadPreload = TIM_AUTORELOAD_PRELOAD_DISABLE;
  if (HAL_TIM_Base_Init(&htim3) != HAL_OK)
  {
    Error_Handler();
  }
  sClockSourceConfig.ClockSource = TIM_CLOCKSOURCE_INTERNAL;
  if (HAL_TIM_ConfigClockSource(&htim3, &sClockSourceConfig) != HAL_OK)
  {
    Error_Handler();
  }
  sMasterConfig.MasterOutputTrigger = TIM_TRGO_UPDATE;
  sMasterConfig.MasterSlaveMode = TIM_MASTERSLAVEMODE_DISABLE;
  if (HAL_TIMEx_MasterConfigSynchronization(&htim3, &sMasterConfig) != HAL_OK)
  {
    Error_Handler();
  }
}

/**
  * Enable DMA controller clock
  */
static void MX_DMA_Init(void)
{

  /* DMA controller clock enable */
  __HAL_RCC_DMA1_CLK_ENABLE();

  /* DMA interrupt init */
  /* DMA1_Channel1_IRQn interrupt configuration */
  HAL_NVIC_SetPriority(DMA1_Channel1_IRQn, 0, 0);
  HAL_NVIC_EnableIRQ(DMA1_Channel1_IRQn);

}

/**
  * @brief GPIO Initialization Function
  * @param None
  * @retval None
  */
static void MX_GPIO_Init(void)
{
  GPIO_InitTypeDef GPIO_InitStruct = {0};

  /* GPIO Ports Clock Enable */
  __HAL_RCC_GPIOC_CLK_ENABLE();
  __HAL_RCC_GPIOF_CLK_ENABLE();
  __HAL_RCC_GPIOA_CLK_ENABLE();
  __HAL_RCC_GPIOB_CLK_ENABLE();

  /*Configure GPIO pin Output Level */
  HAL_GPIO_WritePin(GPIOB, LED_R_Pin|LED_G_Pin|LED_B_Pin, GPIO_PIN_RESET);

  /*Configure GPIO pins : LED_R_Pin LED_G_Pin LED_B_Pin */
  GPIO_InitStruct.Pin = LED_R_Pin|LED_G_Pin|LED_B_Pin;
  GPIO_InitStruct.Mode = GPIO_MODE_OUTPUT_PP;
  GPIO_InitStruct.Pull = GPIO_NOPULL;
  GPIO_InitStruct.Speed = GPIO_SPEED_FREQ_LOW;
  HAL_GPIO_Init(GPIOB, &GPIO_InitStruct);

}

/**
  * @brief  This function is executed in case of error occurrence.
  * @retval None
  */
void Error_Handler(void)
{
  /* User can add his own implementation to report the HAL error return state */
  __disable_irq();
  while (1)
  {
  }
}
#ifdef USE_FULL_ASSERT
/**
  * @brief  Reports the name of the source file and the source line number
  *         where the assert_param error has occurred.
  * @param  file: pointer to the source file name
  * @param  line: assert_param error line source number
  * @retval None
  */
void assert_failed(uint8_t *file, uint32_t line)
{

}
#endif /* USE_FULL_ASSERT */

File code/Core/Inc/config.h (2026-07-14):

/**
 * @file    config.h
 * @brief   Centralized configuration parameters and constants.
 *
 * @details This header defines all tunable system variables, physical constants, 
 * hardware limits (such as servo PWM values and angles), system timing constraints, 
 * and DSP thresholds. Centralizing these parameters allows for easy compile-time 
 * adjustments without modifying the core application logic.
 */

#ifndef CONFIG_H
#define CONFIG_H

// Physical quantities
#define MIC_DISTANCE            0.15f     // Spacing between microphones [m]
#define SPEED_OF_SOUND          343.0f    // Speed of sound in air [m/s]
#define SAMPLE_FREQUENCY_HZ     50000.0f  // ADC sampling rate [Hz]
#define PI                      3.14159   // value of PI

// System settings
#define INACTIVITY_TIMEOUT      5000      // Time to reset to center [ms]
#define AUDIO_BUFFER_SIZE       1024      // Number of samples per channel
#define SETTLING_TIME           100       // Settling time after actuation [ms]
#define BEAM_SETUP_DELAY        5000      // Delay after boot to allow for servo setup [ms]
#define OUT_OF_BOUNDS_DELAY     1000      // Delay after out of bounds detection [ms]

// Hardware settings
#define SERVO_SPEED             1.0f      // Servo speed reduction factor [0.0 - 1.0]. if 1.0 the servo moves at max speed
#define SERVO_MIN_ANGLE         0.0f      // Minimum servo angle [rad]
#define SERVO_MAX_ANGLE         PI        // Maximum servo angle [rad]
#define SERVO_MIN_PWM           500       // Equivalent to 500 us with  current tim2 setup      
#define SERVO_MAX_PWM           2500      // Equivalent to 2500 us with current tim2 setup
#define QUIET_ROOM_TRESHOLD     900      // Minimum value for a sound to qialify as such

// Derived constants
#define MAX_SAMPLE_LAG          ((uint16_t)((MIC_DISTANCE / SPEED_OF_SOUND) * SAMPLE_FREQUENCY_HZ) + 1)
#define TOTAL_DMA_BUFFER_SIZE   (AUDIO_BUFFER_SIZE * 2) // Total size for stereo data
#define SERVO_CENTER_ANGLE      (SERVO_MAX_ANGLE + SERVO_MIN_ANGLE) / 2.0f

#endif // CONFIG_H

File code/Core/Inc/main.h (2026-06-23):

/* Define to prevent recursive inclusion -------------------------------------*/
#ifndef __MAIN_H
#define __MAIN_H

#ifdef __cplusplus
extern "C" {
#endif

/* Includes ------------------------------------------------------------------*/
#include "stm32u0xx_hal.h"

#include "stm32u0xx_nucleo.h"
#include <stdio.h>

void HAL_TIM_MspPostInit(TIM_HandleTypeDef *htim);

/* Exported functions prototypes ---------------------------------------------*/
void Error_Handler(void);

/* Private defines -----------------------------------------------------------*/
#define OSC32_IN_Pin GPIO_PIN_14
#define OSC32_IN_GPIO_Port GPIOC
#define OSC32_OUT_Pin GPIO_PIN_15
#define OSC32_OUT_GPIO_Port GPIOC
#define OSC_IN_Pin GPIO_PIN_0
#define OSC_IN_GPIO_Port GPIOF
#define OSC_OUT_Pin GPIO_PIN_1
#define OSC_OUT_GPIO_Port GPIOF
#define LED_R_Pin GPIO_PIN_13
#define LED_R_GPIO_Port GPIOB
#define LED_G_Pin GPIO_PIN_14
#define LED_G_GPIO_Port GPIOB
#define LED_B_Pin GPIO_PIN_15
#define LED_B_GPIO_Port GPIOB
#define SWDIO_Pin GPIO_PIN_13
#define SWDIO_GPIO_Port GPIOA
#define SWCLK_Pin GPIO_PIN_14
#define SWCLK_GPIO_Port GPIOA


#ifdef __cplusplus
}
#endif

#endif /* __MAIN_H */

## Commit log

2026-06-13 added materials sourcing
2026-06-17 refactored project workload & pitch presentation
2026-06-18 Update README with improved configuration description
    Refine STM32CubeMX peripheral configuration details.
2026-06-21 Modify DMA stream configuration in README
    Updated DMA stream configuration from circular to normal mode in the README.
2026-06-23 Fix LED behavior
    Updated state descriptions and corrected component details in the README.
2026-06-23 implemented micrphone data collector
    [sample_0_quiet_room_baseline.csv, sample_1_sound_from_the_right.csv, sample_2_sound_at_center.csv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]
2026-06-23 changed PWM from pin PA0 to PA15
2026-06-24 refactored workspace
    [Bar2.SLDPRT, Bar2.STL, Base2.SLDPRT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]
2026-06-25 added 6 sec delay to center dhe beam on the servo
2026-06-25 tested pipeline and it is wrong
    [correlation_filtered.csv, correlation_raw.csv, sample_1_filtered.csv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]
2026-06-25 fixed filtering algorythm
    [correlation_filtered.csv, correlation_raw.csv, sample_1_filtered.csv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]
2026-06-26 tested signal filtering with 5500 hz noise
    [correlation_filtered.csv, correlation_raw.csv, sample_0_quiet_room_baseline.csv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]
2026-07-02 implemented 6th order filter
2026-07-02 added documentation
    [correlation_filtered.csv, correlation_raw.csv, sample_0_quiet_room_baseline.csv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]
2026-07-05 added report
    * technical report section 2
    * Refactor main.c to improve structure and readability
    * Update main.c
    * chapter 3
    * diagram test
    * diagram test
    * added fsm to readme
    * minor changes
    * done chapter 6
    * minor corrections
    * minor corrections
    * added suggestions
    * Add files via upload
    * Update techincal_report.md
    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
    [sample_1_raw.csv]
2026-07-09 Implemented servo speed control
2026-07-14 Finalized report
    * added protorypes gifs
    * Rename CAD Portfolio.png to exploded_view.png
    * addedimage of final robot
    * Update image path for exploded view in README
    ---------
    added demo video
    Fix video link in technical report
    Updated the video link for the real-time demonstration of the robotic hearing system to point to the correct GitHub location.
    Enhance README with setup and build instructions
    Updated README with detailed setup, build, and flashing instructions for Ubuntu 22.04, including prerequisites and repository cloning steps.
    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
    [config.h]
2026-07-15 Fix sample lag in technical report figure description
    Corrected the sample lag in the figure description from 24 to 22 samples for accurate TDOA calculation.
